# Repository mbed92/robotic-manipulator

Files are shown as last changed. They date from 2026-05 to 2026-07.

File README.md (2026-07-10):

# robotic-manipulator

Robotic manipulator prototype on a workbench

A small robotic manipulator project controlled by an Arduino Nano through a
PCA9685 servo driver. The repository contains Arduino firmware, the kinematic
model, angle-to-PWM mapping, calibration constants, and PCB files. This is my side project, 
and I had a lot of fun working on it. 

## Structure

- [`arduino/robot_arm/robot_arm.ino`](arduino/robot_arm/robot_arm.ino) - main firmware sketch.
- [`arduino/robot_arm/kinematics.h`](arduino/robot_arm/kinematics.h) / [`kinematics.cpp`](arduino/robot_arm/kinematics.cpp) - forward kinematics, Jacobian IK step generation, and angle-to-PWM conversion.
- [`arduino/robot_arm/robot_calibration.h`](arduino/robot_arm/robot_calibration.h) - servo channels, joint limits, HOME pose, and arm dimensions.
- [`arduino/robot_arm/pca9685_servo_driver.h`](arduino/robot_arm/pca9685_servo_driver.h) / [`pca9685_servo_driver.cpp`](arduino/robot_arm/pca9685_servo_driver.cpp) - PCA9685 driver wrapper.
- [`docs/bom.md`](docs/bom.md) - V1 prototype bill of materials.
- [`docs/lessons-learned.md`](docs/lessons-learned.md) - practical notes from calibration, IK debugging, and wiring.
- [`docs/TODO.md`](docs/TODO.md) - project task notes and planned improvements.
- [`pcb/`](pcb/) - KiCad PCB project.

## Hardware

The firmware assumes:

- an Arduino Nano microcontroller,
- a PCA9685 PWM driver on the I2C bus,
- six logical joints `J0-J5`, where `J0-J4` are part of the kinematic model
  and `J5` is the gripper.

The mechanical design and servo selection are based on material from
[Elektroweb](https://elektroweb.pl).

Joint indices map to PCA9685 channels defined in
`arduino/robot_arm/robot_calibration.h`.

## Kinematic Model

The manipulator is modeled as an arm with five kinematic joints:

- `J0` - base rotation around the vertical axis,
- `J1-J3` - pitch joints forming the planar arm chain,
- `J4` - local wrist/TCP rotation, independent of TCP position in the current model,
- `J5` - gripper, controlled outside the kinematic model.

TCP position is represented by the `TcpPose` structure:

- `reach_x_m` - reach in the arm plane, in meters,
- `reach_z_m` - TCP height, in meters,
- `yaw_rad` - base rotation, in radians.

Angle convention:

- all angles are in radians,
- `J1-J3 = 0` means that the arm segments point vertically upward,
- positive horizontal reach is computed with `sin(angle)`,
- height is computed with `cos(angle)`,
- `J0` controls the yaw of the whole arm,
- `J4` does not change the TCP position reported by forward kinematics.

Arm dimensions are stored in `JOINT_OFFSETS`:

- `L1` - vertical distance from base `J0` to shoulder `J1`,
- `L2-L4` - planar arm segment lengths,
- `L5` - offset from the last link to the TCP.

## Forward Kinematics

`forwardKinematics()` takes `J0-J4` joint angles and returns a `TcpPose`.
The computation accumulates consecutive pitch angles:

- `pitch_1 = J1`,
- `pitch_2 = J1 + J2`,
- `pitch_3 = J1 + J2 + J3`.

The TCP reach and height are then computed from link lengths `L2-L5`.
In the current model, `L4` and `L5` have the same direction as the final pitch
`J1 + J2 + J3`.

## Inverse Kinematics

The firmware uses an open-loop Jacobian IK trajectory generator based on the
commanded joint state:

- `computeJacobianIkStep()` is a pure numerical function. It computes one IK
  step from the current commanded joint angles, target, and configuration. It
  does not write PWM, wait, or access hardware.
- `moveToTargetJacobianIk()` in `robot_arm.ino` is the blocking hardware-facing
  trajectory generator. It calls the step function, checks limits, converts the
  next angles to PWM, writes the PCA9685 channels, waits until the next control
  period, and updates the commanded joint state.
- Before the planar DLS loop, the generator moves the explicitly commanded
  `J0`, `J3`, and `J4` axes toward their targets with the same fixed period and
  velocity limits. This gives the local Jacobian solve the intended `J3`
  geometry instead of starting from the vertical HOME singularity.

The IK task is:

- TCP reach,
- TCP height,
- base yaw,
- explicit `J3`,
- explicit `J4`.

Only the coupled planar subproblem `[reach, height, J3] <-> [J1, J2, J3]`
uses damped least squares. `J0` yaw and `J4` are handled as direct proportional
controllers with the same joint velocity and joint limit handling as the planar
joints. Task rows have explicit weights so meter and radian errors are scaled
before the DLS solve.

The solver limits joint velocity by computing a global `alpha` scale. If any
requested joint velocity exceeds its limit, the whole `q_dot` vector is scaled
by the smallest required ratio. For example, if a joint requests `3 rad/s` and
the limit is `2 rad/s`, the whole command is scaled by `2/3`. The current
default joint velocity limit is `0.5 rad/s` for each kinematic joint.

The default motion configuration uses a `20 ms` control period and allows up to
`500` iterations per target. With the default period this gives a maximum of
about `10 s` for one blocking target move before the target is reported as not
converged.

Joint limits also shrink the global step before failing the motion. A target is
reported as blocked only when the step scale is effectively exhausted while the
task error is still too large. The blocking motion loop also detects lack of
progress so the robot does not spend several seconds making tiny noisy motions
near an unreachable target.

Damped least squares does not remove physical singularities. Near a singular
configuration, some TCP directions are still not achievable by the mechanism.
DLS only prevents the numerical controller from asking for unbounded joint
velocities.

Because `J3` is an explicit task requirement and also part of the reach/height
kinematics, it restricts the reachable workspace. Some points that are
geometrically reachable with free `J3` may not be reachable when a specific
`J3` value is required.

Possible error statuses include:

- `OutOfReach` - the target did not converge within the configured iteration budget,
- `JointLimitViolation` - the current or computed command violates joint limits,
- `JointLimitBlocked` - joint limits prevent useful progress toward the target,
- `NoProgress` - the solver stopped reducing the normalized task error,
- `InvalidInput` - the input contains invalid values, such as `NaN` or infinity.

## Control Rules

The current firmware executes a fixed pick-and-place demo sequence during
startup:

1. `TARGET1` through `TARGET11` in `robot_arm.ino` define target `TcpPose`
   values, explicit `J3`, explicit `J4`, and gripper state.
2. `setup()` initializes the PCA9685, sends the arm to `ZERO`/HOME, and opens
   the gripper.
3. The robot moves through a blocking fixed-period Jacobian IK sequence: ready
   pose, pick-side yaw, descend, close gripper, lift, carry across a larger
   base rotation, descend, open gripper, retreat, and return to HOME.
4. The final HOME return is a normal Jacobian IK target, not a direct
   all-servo zero command.
5. Once the sequence is complete, `loop()` stays idle.

This is not closed-loop feedback from joint sensors. It is an open-loop
trajectory generator that assumes the commanded state is a reasonable estimate
of the servo state. Every new target and transition should still be tested
carefully on hardware.

## V1 Limitations

- No closed-loop feedback from joints.
- The Jacobian IK trajectory generator is blocking during the fixed demo
  sequence.
- IK solves TCP position and base yaw, not full 6D pose.
- `J3` and `J4` are explicit task inputs; `J3` constrains reachable TCP
  positions.
- Calibration is specific to this physical build and should not be copied
  blindly.
- Servo limits are conservative to avoid mechanical stops.

## Angle-To-PWM Mapping

`jointAnglesToPwmUs()` uses calibration values from `JOINT_CALIBRATIONS`.
For each joint, the calibration defines:

- PCA9685 channel,
- `pwm_min_us`, `pwm_zero_us`, `pwm_max_us`,
- `angle_min_rad`, `angle_zero_rad`, `angle_max_rad`.

The mapping is piecewise linear:

- from `angle_min_rad` to `angle_zero_rad`,
- from `angle_zero_rad` to `angle_max_rad`.

This also supports reversed servos, for example when `pwm_min_us` is greater
than `pwm_max_us`. The current `J3` calibration is one such case.

The `J5` gripper is controlled separately:

- `Open` uses `pwm_min_us`,
- `Closed` uses `pwm_max_us`.

## Lessons Learned

The main practical lessons are:

- mechanical zero is set by servo horn mounting first, then refined with
  `pwm_zero_us`,
- each joint needs its own zero, min, max, sign direction, and mechanical-stop
  check,
- IK commands should be sanity-checked by running FK on the resulting joint
  angles,
- Arduino logic power and servo power should be separated, with a common ground.

See [`docs/lessons-learned.md`](docs/lessons-learned.md) for the detailed notes.

## Startup Safety

Before testing on the manipulator, check:

- whether the target is within `JOINT_CALIBRATIONS` limits,
- whether `J3` and `J4` can cause a mechanical collision,
- whether the gripper PWM values are calibrated correctly,
- whether the open-loop IK motion can hit mechanical stops,
- whether the servo power supply is sufficient for multi-joint motion under load.

The safest test sequence is to compile first, then test without load, and only
then move with the final tool or object.

## Related Material

For broader teaching material on forward and inverse kinematics, see
[robotics-ai-classes](https://github.com/mbed92/robotics-ai-classes). That
repository contains ROS-based class exercises for FK and IK on a robotic
manipulator.

## Validation

Use Arduino CLI to validate firmware before testing on hardware:

```sh
arduino-cli compile --fqbn arduino:avr:nano arduino/robot_arm
```

For throwaway local builds, specify an explicit build path so generated
artifacts do not end up in the repository:

```sh
arduino-cli compile --fqbn arduino:avr:nano --build-path /tmp/robot_arm_build arduino/robot_arm
```

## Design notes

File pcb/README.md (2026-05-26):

# PCB Wiring

## Connections

- Laptop USB -> Arduino USB
- Arduino +5V -> PCA9685 VCC/VDD
- Arduino GND -> PCA9685 GND/VSS
- Arduino SDA (pin A4) -> PCA9685 SDA
- Arduino SCL (pin A5) -> PCA9685 SCL
- PSU +5V -> PCA9685 V+
- PSU GND -> PCA9685 GND
- SERVO1..6 PWM -> PCA9685 CH1..6 PWM
- SERVO1..6 5V -> PCA9685 CH1..6 5V
- SERVO1..6 GND -> PCA9685 CH1..6 GND

## Important Notes

- Arduino does NOT power the servos.
- Servos are powered directly from PSU.
- All grounds must be connected together.
- PCA9685 generates hardware PWM signals.

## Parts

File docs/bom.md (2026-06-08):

# Bill of Materials

This document lists the main components used in the V1 desktop robotic manipulator build.

The goal of this BOM is not to define a production-ready design, but to document the exact hardware used for the first working prototype.

## Main hardware

| Category | Component | Model / specification | Qty | Role in project | Notes |
| --- | --- | ---: | ----: | --- | --- |
| Mechanical kit | 6DOF robotic arm kit | Metal 6DOF arm with gripper | 1 | Main robot structure | Includes metal frame, gripper, servo horns, screws, bearings, cable sleeving and zip ties. |
| Servo | High-torque servo | MG996R | 6 | Arm joints and gripper actuation | Hobby servos used for all actuated joints. Real range and zero position must be calibrated per joint. |
| Controller | Arduino-compatible board | DFRduino Nano V4.0 / Arduino Nano compatible | 1 | Main microcontroller | Runs FK/IK, calibration mapping and servo commands. |
| Servo PWM driver | PCA9685 PWM servo driver | I2C PWM driver | 1 | Generates PWM signals for servos | Driven over I2C from Arduino. Servo power must be provided separately through the servo power rail. |
| Power supply | AC/DC switching PSU | POS-50-5-C2, 5 V / 10 A / 50 W | 1 | Main 5 V power supply for servos | Provides power for the servo rail. Do not power the servos from Arduino 5 V. |
| Servo tester | 3-channel servo tester | Generic 3-channel tester | 1 | Manual servo testing and centering | Used before connecting servos to PCA9685. Useful for checking servo health and approximate range. |
| Multimeter | Digital multimeter | UNI-T UT33A+ | 1 | Voltage and continuity checks | Used to verify PSU output, common GND and basic wiring. |
| Capacitor | Electrolytic capacitor | 1000 µF / 25 V, THT | 5 | Servo rail decoupling | Used near the servo power rail to reduce voltage dips caused by servo load transients. |
| Switch | Rocker switch | IRS-101-8C/D, 12 VDC / 20 A | 1 | Manual power switch | Used as a convenient switch in the prototype. Check ratings carefully before using in a final build. |
| Cable | USB cable | microUSB B to USB-A | 1 | Arduino programming and serial monitor | Used for firmware upload and debug output. |
| Wires | Jumper wires | 20 cm M-M, F-F, M-F set | 1 set | Low-current signal wiring | Useful for I2C and prototype wiring. Do not use thin jumpers for high-current servo power distribution. |

## Servo details

| Parameter | Value | Notes |
| --- | ---: | --- |
| Servo model | MG996R | Metal gear hobby servo. |
| Nominal operating voltage  | 4.8–7.2 V | The V1 build uses a 5 V supply. |
| Recommended kit voltage | 5–6 V | Matches the mechanical kit recommendation. |
| Approximate rotation range | ~120° | Treat this as approximate. Actual usable range depends on mechanical mounting and joint limits. |
| Stall current | ~2.5 A at 6 V | Important for power sizing. Multiple servos can create large transient current draw. |
| Signal period | 20 ms / 50 Hz | Standard hobby servo PWM. |
| Signal wire | Yellow / orange | PWM signal. |
| Power wire | Red | Servo VCC. |
| Ground wire | Brown | Servo GND. |

## Power architecture

The prototype uses separated logic and servo power:

| Rail | Source | Consumers | Notes |
| --- | --- | --- | --- |
| Logic 5 V | Arduino USB / Arduino 5 V rail | Arduino, PCA9685 logic side | Used only for logic-level electronics.  |
| Servo 5 V | External 5 V / 10 A PSU | PCA9685 servo V+ rail, servos | Used for servo power. |
| GND | Common ground | Arduino, PCA9685, PSU, servos | All grounds must be connected together. |

Important wiring rule:

```text
Arduino GND  --------+
PCA9685 GND ---------+---- common GND
PSU GND ------------+
Servo GND ----------+
```

The servos must not be powered directly from the Arduino 5 V pin. The Arduino controls the PWM driver, but the servo current comes from the external PSU.

## Wiring summary

| Connection | From | To | Notes |
| --- | --- | --- | --- |
| I2C SDA | Arduino SDA / A4 | PCA9685 SDA | Logic signal. |
| I2C SCL | Arduino SCL / A5 | PCA9685 SCL | Logic signal. |
| Logic power | Arduino 5 V | PCA9685 VCC / VDD | Logic power only. |
| Common ground | Arduino GND | PCA9685 GND, PSU GND | Required for PWM signal reference. |
| Servo power | PSU +5 V | PCA9685 V+ | High-current servo rail. |
| Servo ground  | PSU GND | PCA9685 GND / servo GND | Shared return path. |
| Servo PWM | PCA9685 channel PWM | Servo signal wire | One channel per servo. |

## Tools and consumables

| Component | Purpose | Notes |
| --- | --- | --- |
| Multimeter | Voltage, polarity and continuity checks | Verify 5 V before connecting servos. |
| Servo tester | Manual servo range and centering tests  | Useful before writing firmware. |
| Jumper wires | Prototype signal wiring | Use only for low-current paths. |
| Thicker power wires | Servo power distribution | Recommended for PSU-to-servo power bus. |
| Zip ties / sleeving | Cable management | Cables must not restrict joint motion.  |
| Small screwdriver set | Mechanical assembly | Required for frame and servo horns. |

## Known substitutions

| Original component | Possible substitute | Requirements |
| --- | --- | --- |
| DFRduino Nano V4.0 | Arduino Nano / Uno compatible | Must support I2C and Arduino Servo/PWM-related libraries. |
| PCA9685 PWM board  | Any PCA9685 16-channel servo driver | Must expose VCC/VDD, V+, GND, SDA, SCL and servo headers. |
| 5 V / 10 A PSU | Other 5–6 V DC PSU | Must provide enough current for multiple servos. Use current margin. |
| MG996R servos | Similar metal gear hobby servos | Requires recalibration of PWM limits, zero positions and joint directions. |

## Safety notes

* Verify PSU output voltage before connecting the servo rail.
* Do not power the servos from the Arduino.
* Keep all grounds common.
* Start with one servo connected during early tests.
* Keep PWM limits conservative until each joint is calibrated.
* Check that cables do not restrict motion at any joint.
* Keep a physical way to cut servo power during first motion tests.

## V1 limitations

This BOM describes the first working prototype. It is not a production-ready electrical design.

Known limitations:

* No current sensing on individual servos.
* No emergency stop circuit.
* No fuse selected specifically for the final DC servo rail.
* No dedicated high-current PCB or power distribution board.
* Servo power distribution is prototype-grade.
* Cable strain relief should be improved before extended operation.
* Servo calibration is specific to this mechanical build.

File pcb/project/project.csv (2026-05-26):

Reference | Qty | Value | DNP | Exclude from BOM | Exclude from Board | Footprint | Datasheet
A1 | 1 | Arduino_Nano_v3.x |  |  |  | Module:Arduino_Nano | http://www.mouser.com/pdfdocs/Gravitech_Arduino_Nano3_0.pdf
C1 | 1 | 1000uF / 25V |  |  |  | Capacitor_THT:CP_Radial_D10.0mm_P5.00mm
J1 | 1 | PCA9685_I2C |  |  | Wykluczono z płytki
J2 | 1 | SERVO_BASE |  |  |  | Connector_PinHeader_2.54mm:PinHeader_1x03_P2.54mm_Vertical
J3 | 1 | SERVO_SHOULDER |  |  |  | Connector_PinHeader_2.54mm:PinHeader_1x03_P2.54mm_Vertical
J4 | 1 | SERVO_ELBOW |  |  |  | Connector_PinHeader_2.54mm:PinHeader_1x03_P2.54mm_Vertical
J5 | 1 | SERVO_WRIST_PITCH |  |  |  | Connector_PinHeader_2.54mm:PinHeader_1x03_P2.54mm_Vertical
J6 | 1 | SERVO_WRIST_ROT |  |  |  | Connector_PinHeader_2.54mm:PinHeader_1x03_P2.54mm_Vertical
J7 | 1 | SERVO_GRIPPER |  |  |  | Connector_PinHeader_2.54mm:PinHeader_1x03_P2.54mm_Vertical
J8 | 1 | PWM1 |  |  | Wykluczono z płytki
J9 | 1 | PWM2 |  |  | Wykluczono z płytki
J10 | 1 | PWM3 |  |  | Wykluczono z płytki
J11 | 1 | PWM4 |  |  | Wykluczono z płytki
J12 | 1 | PWM5 |  |  | Wykluczono z płytki
J13 | 1 | PWM6 |  |  | Wykluczono z płytki
J14 | 1 | POS-50-5-C2 |  |  |  | TerminalBlock:TerminalBlock_MaiXu_MX126-5.0-02P_1x02_P5.00mm

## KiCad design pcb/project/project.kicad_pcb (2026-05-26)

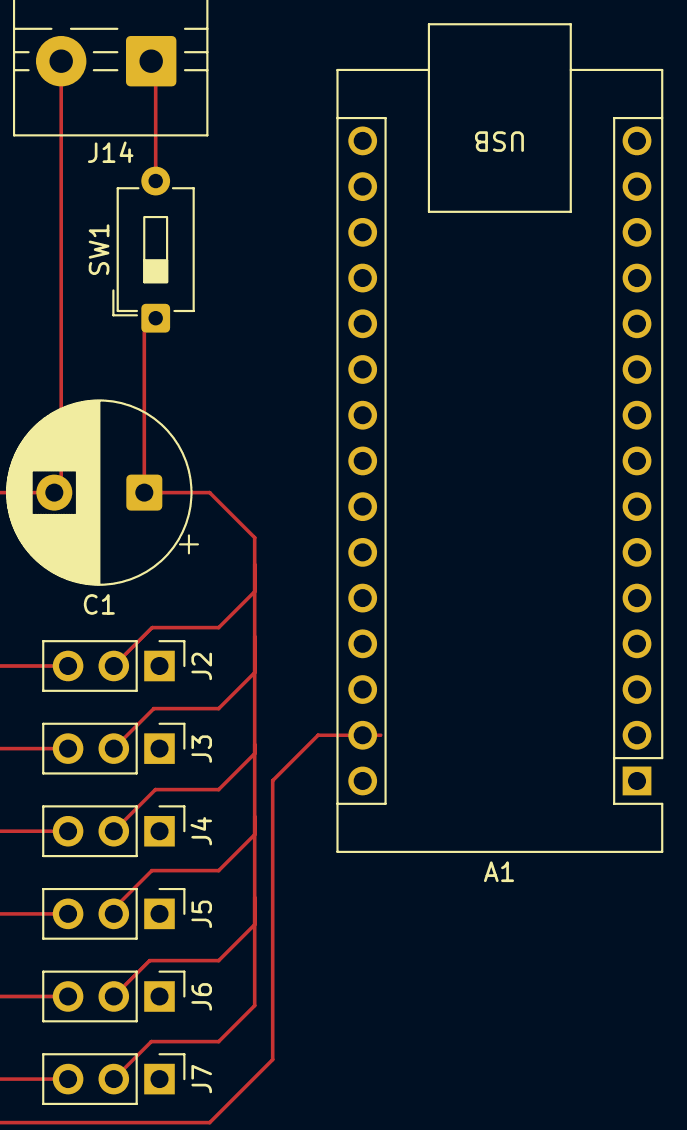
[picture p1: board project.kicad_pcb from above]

Board: 2 copper layers, 10 parts (0 on the bottom side), 3 nets.

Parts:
A1: Arduino_Nano_v3.x; Arduino_Nano
C1: 1000uF / 25V; CP_Radial_D10.0mm_P5.00mm
J2: SERVO_BASE; PinHeader_1x03_P2.54mm_Vertical
J3: SERVO_SHOULDER; PinHeader_1x03_P2.54mm_Vertical
J4: SERVO_ELBOW; PinHeader_1x03_P2.54mm_Vertical
J5: SERVO_WRIST_PITCH; PinHeader_1x03_P2.54mm_Vertical
J6: SERVO_WRIST_ROT; PinHeader_1x03_P2.54mm_Vertical
J7: SERVO_GRIPPER; PinHeader_1x03_P2.54mm_Vertical
J14: POS-50-5-C2; TerminalBlock_MaiXu_MX126-5.0-02P_1x02_P5.00mm
SW1: SW_SPST; SW_DIP_SPSTx01_Slide_6.7x4.1mm_W7.62mm_P2.54mm_LowProfile

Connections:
/+5V_IN: J14.1, SW1.2 (B)
/+5V_SERVO: C1.1, J2.2, J3.2, J4.2, J5.2, J6.2, J7.2, SW1.1 (A)
/GND: A1.29 (GND), C1.2, J2.3, J3.3, J4.3, J5.3, J6.3, J7.3, J14.2

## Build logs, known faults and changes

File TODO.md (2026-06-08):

# TODO

## Accept target commands from an external controller

Current state:
- The firmware uses a manually edited `const ArmTarget TARGET` in `robot_arm.ino`.
- Changing the target TCP pose, `J3`, `J4`, or gripper state requires editing and reflashing the Arduino sketch.
- This is useful for a simple bring-up demo, but it is not a practical control interface.

Target state:
- Receive target commands from an external controller over a board-level bus such as I2C or SPI.
- The external controller could be ROS running on a Jetson or PC.
- Keep the Arduino responsible for low-level command validation, IK, angle-to-PWM conversion, and servo output.
- Keep the higher-level system responsible for planning, sequencing, and deciding what target should be sent next.

Recommended first implementation:
- Define a small binary command frame for `TcpPose`, requested `J3`, requested `J4`, and gripper command.
- Include a protocol version, command type, payload length, and checksum or CRC.
- Return an explicit status response such as accepted, invalid input, out of reach, or joint limit violation.
- Start with one command-at-a-time execution before adding queues or streaming trajectories.

Main trade-off:
- I2C is simple and common for embedded peripherals, but the Arduino must behave predictably as a bus device.
- SPI can provide cleaner timing and higher throughput, but needs more wiring and a slightly stricter framing design.
- A serial transport may be easier for early debugging, even if I2C or SPI remains the target hardware interface.

## Generate coordinated multi-joint ramps

Current state:
- Ramp generation is disabled for now.
- `Pca9685ServoDriver::setServoUs()` writes the target PWM immediately.
- Demo scripts still call `setServoUs()` joint by joint, but each call is now a direct PWM update.

Target state:
- Generate the ramp at the motion/script level, where targets for all joints are known at the same time.
- Keep the PCA9685 driver focused on low-level PWM output, using immediate channel writes for each ramp sample.
- For each ramp step, compute intermediate PWM values for all joints and write all channels before delaying.

Recommended first implementation:
- Add a helper such as `moveAllJointsRamp(targets_us)` in the main demo/control script.
- Read or track the current PWM for each joint.
- Compute the maximum required delta across all joints.
- Step from current values to target values proportionally so all joints finish together.
- Use `setServoUsImmediate()` for each channel inside each ramp sample.

Main trade-off:
- A blocking `moveAllJointsRamp()` is acceptable as a simple first step and fixes sequential joint motion.
- A later version should use a non-blocking `millis()`-based trajectory update if the robot needs responsiveness to commands, sensors, or emergency stop handling during motion.

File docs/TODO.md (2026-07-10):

# TODO

## Accept target commands from an external controller

Current state:
- The firmware uses a hardcoded `TARGETS[]` pick-and-place demo sequence in `robot_arm.ino`.
- Changing the target TCP pose, `J3`, `J4`, or gripper state requires editing and reflashing the Arduino sketch.
- This is useful for local demo tuning, but it is not a practical control interface.

Target state:
- Receive target commands from an external controller over a board-level bus such as I2C or SPI.
- The external controller could be ROS running on a Jetson or PC.
- Keep the Arduino responsible for low-level command validation, IK, angle-to-PWM conversion, and servo output.
- Keep the higher-level system responsible for planning, sequencing, and deciding what target should be sent next.

Recommended first implementation:
- Define a small binary command frame for `TcpPose`, requested `J3`, requested `J4`, and gripper command.
- Include a protocol version, command type, payload length, and checksum or CRC.
- Return an explicit status response such as accepted, invalid input, out of reach, or joint limit violation.
- Start with one command-at-a-time execution before adding queues or streaming trajectories.

Main trade-off:
- I2C is simple and common for embedded peripherals, but the Arduino must behave predictably as a bus device.
- SPI can provide cleaner timing and higher throughput, but needs more wiring and a slightly stricter framing design.
- A serial transport may be easier for early debugging, even if I2C or SPI remains the target hardware interface.

## Make Jacobian IK motion non-blocking

Current state:
- The main demo uses a blocking open-loop Jacobian IK trajectory generator.
- Each generated step writes all kinematic joint PWM targets, waits until the next fixed control period, and updates the commanded joint state.
- `Pca9685ServoDriver::setServoUs()` remains a low-level immediate PWM write.

Target state:
- Keep `computeJacobianIkStep()` as a pure numerical function.
- Move the blocking loop into a non-blocking `millis()`-scheduled motion state machine when the robot needs to accept commands, status requests, or stop conditions during motion.
- Keep the PCA9685 driver focused on low-level PWM output.

Recommended first implementation:
- Define an active motion state containing target, config, last deadline, current commanded angles, last error, and no-progress counter.
- On each loop tick, run at most one Jacobian IK step when the next period deadline has elapsed.
- Return explicit status for running, converged, invalid input, joint-limit blocked, no progress, and missed deadline.
- Add a way to cancel the active motion before adding command queues.

Main trade-off:
- The current blocking implementation is simpler for bring-up and keeps timing easy to inspect.
- A non-blocking scheduler is more complex, but it is needed before the Arduino can safely handle external command streaming or emergency-stop style inputs during motion.

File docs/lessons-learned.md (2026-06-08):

# Lessons Learned

This project is hardware-adjacent, so the useful lessons are mostly about
keeping the software model honest against the physical manipulator.

## Servo Zero Is Mechanical First

`1500 us` does not automatically mean a good-looking robot pose. It is only the
electrical midpoint of a typical hobby servo command range.

Mechanical zero should be established by mounting each servo horn so the joint
is physically at its intended zero position when the servo is commanded to its
zero PWM. Only after that should `pwm_zero_us` be calibrated in
`arduino/robot_arm/robot_calibration.h`.

If the horn is installed one spline off, software calibration can hide the
symptom, but the usable range becomes asymmetric. The joint can then hit a
mechanical stop before the configured software limit is reached.

## Servo Range Is Not Always 180 Degrees

The real MG996R range does not have to match a full 180 degrees. A commonly
referenced MG996R datasheet describes about 120 degrees of movement, which is
roughly 60 degrees in each direction from center:
[MG996R datasheet](https://mm.digikey.com/Volume0/opasdata/d220001/medias/docus/204/MG996R.pdf).

That is why the current calibration uses conservative joint limits of about
`-60` to `+60` degrees:

```cpp
constexpr float JOINT_ANGLE_MIN_RAD = -1.0472f; // -60 degrees
constexpr float JOINT_ANGLE_MAX_RAD = 1.0472f; // 60 degrees
```

This is a practical safety choice, not just a kinematic preference. It keeps
software commands closer to the range the servos and mechanism can actually
reach.

## Calibrate Every Joint Separately

Each joint needs its own calibration pass:

- physical zero,
- minimum safe PWM and angle,
- maximum safe PWM and angle,
- sign direction,
- mechanical-stop margin.

Do not assume that all servos are mounted with the same direction. In this
project, `J3` is reversed in `JOINT_CALIBRATIONS`:

```cpp
{3, 2000, 1500, 1000, JOINT_ANGLE_MIN_RAD, JOINT_ANGLE_ZERO_RAD, JOINT_ANGLE_MAX_RAD},
```

That is intentionally different from the normal ordering used by most other
joints:

```cpp
{0, 1000, 1500, 2000, JOINT_ANGLE_MIN_RAD, JOINT_ANGLE_ZERO_RAD, JOINT_ANGLE_MAX_RAD},
```

The reversed PWM order is clearer and safer than compensating for the inversion
somewhere else in the kinematic code.

## Verify IK With FK

Inverse kinematics should be debugged by comparing the requested IK target with
the forward-kinematics result of the computed joint angles.

The firmware already does this in `robot_arm.ino`: after solving IK and
converting the command, it runs `forwardKinematics(angles)` and prints the
model TCP pose. That makes it easier to catch:

- sign errors,
- wrong link lengths,
- joint-limit surprises,
- IK solutions that are mathematically valid but not the solution expected on
  the real arm.

This is one of the most useful checks before trusting a new target on hardware.

## Keep The Kinematic Model As Simple As The Robot

The kinematic model should match the actual mechanism instead of solving a more
general problem than the robot needs.

In this project, the IK can stay simple:

- `J0` provides independent yaw,
- `J1-J3` form a planar `Reacher2D` chain,
- `J4` is a user-defined local wrist/TCP rotation,
- `J5` is the gripper and is controlled outside the kinematic model.

This keeps the firmware easier to debug and reduces the number of ambiguous IK
solutions.

## Power Wiring Is Part Of The Control System

Common ground and separated power domains are not details. They are conditions
for the robot to work reliably.

The PCB wiring follows this split:

- Arduino powers the PCA9685 logic side through VCC/VDD,
- the external PSU powers PCA9685 `V+` and the servos,
- Arduino ground, PSU ground, PCA9685 ground, and servo grounds are connected
  together.

The Arduino should not power the servos. The servo rail can draw high current
and create voltage drops or resets that should not be imposed on the logic
supply. At the same time, all grounds must be common or the PWM signal has no
shared electrical reference.

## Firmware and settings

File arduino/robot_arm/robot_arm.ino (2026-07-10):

/**
 * Fixed pick-and-place demo sequence.
 *
 * setup() moves the robot to HOME/ZERO, opens the gripper, executes the
 * TARGETS[] sequence with the open-loop Jacobian IK trajectory generator, then
 * returns to HOME through the same controlled motion path. loop() stays idle.
 */

#include <Wire.h>
#include <math.h>

#include "kinematics.h"
#include "pca9685_servo_driver.h"
#include "robot_calibration.h"

enum class GripperCommand {
    Closed,
    Open,
};

struct ArmTarget {
    TcpPose tcp_pose;
    float j3_rad;
    float j4_rad;
    GripperCommand gripper;
};

struct JacobianIkResult {
    KinematicsStatus status;
    uint16_t iterations;
    bool missed_deadline;
    JacobianIkStepResult last_step;
    ArmJointPwmUs last_pwm;
};

const ArmTarget TARGET1 = {
    {0.140f, 0.360f, 0.0f},
    0.900f,
    0.0f,
    GripperCommand::Open,
};

const ArmTarget TARGET2 = {
    {0.140f, 0.360f, -0.95f},
    0.900f,
    -0.7f,
    GripperCommand::Open,
};

const ArmTarget TARGET3 = {
    {0.160f, 0.350f, -0.95f},
    0.900f,
    -0.7f,
    GripperCommand::Open,
};

const ArmTarget TARGET4 = {
    {0.160f, 0.350f, -0.95f},
    0.900f,
    -0.7f,
    GripperCommand::Closed,
};

const ArmTarget TARGET5 = {
    {0.140f, 0.360f, -0.95f},
    0.900f,
    -0.7f,
    GripperCommand::Closed,
};

const ArmTarget TARGET6 = {
    {0.150f, 0.360f, 0.0f},
    0.900f,
    0.0f,
    GripperCommand::Closed,
};

const ArmTarget TARGET7 = {
    {0.140f, 0.360f, 0.95f},
    0.900f,
    0.7f,
    GripperCommand::Closed,
};

const ArmTarget TARGET8 = {
    {0.160f, 0.350f, 0.95f},
    0.900f,
    0.7f,
    GripperCommand::Closed,
};

const ArmTarget TARGET9 = {
    {0.160f, 0.350f, 0.95f},
    0.900f,
    0.7f,
    GripperCommand::Open,
};

const ArmTarget TARGET10 = {
    {0.140f, 0.360f, 0.95f},
    0.900f,
    0.7f,
    GripperCommand::Open,
};

const ArmTarget TARGET11 = {
    {0.0f, 0.489f, 0.0f},
    0.0f,
    0.0f,
    GripperCommand::Open,
};

const ArmTarget TARGETS[] = {
    TARGET1,
    TARGET2,
    TARGET3,
    TARGET4,
    TARGET5,
    TARGET6,
    TARGET7,
    TARGET8,
    TARGET9,
    TARGET10,
    TARGET11,
};

constexpr unsigned long STEP_DELAY_MS = 500;

Pca9685ServoDriver servo_driver;
ArmJointAngles commanded_angles;

bool moveToArmTarget(const char *name, const ArmTarget &target, const JacobianIkConfig &config);
JacobianIkResult moveToTargetJacobianIk(
    ArmJointAngles &commanded_angles,
    const JacobianIkTarget &target,
    const JacobianIkConfig &config);
JacobianIkTarget toJacobianIkTarget(const ArmTarget &target);
void sendZeroCommand();
bool sendKinematicJointCommand(const ArmJointAngles &angles, ArmJointPwmUs &pwm);
void sendGripperCommand(GripperCommand command);
void waitUntilNextPeriod(unsigned long period_start_ms, unsigned long period_ms, bool &missed_deadline);
bool moveExplicitJointTargets(
    ArmJointAngles &commanded_angles,
    const JacobianIkTarget &target,
    const JacobianIkConfig &config,
    JacobianIkResult &result);
float limitedAngleStep(float error_rad, float velocity_limit_rad_s, float dt_s);
float normalizedTaskError(const JacobianIkStepResult &step, const JacobianIkConfig &config);
void printTargetDiagnostics(
    const ArmTarget &target,
    const JacobianIkResult &result,
    const ArmJointAngles &angles);
void printArmJointAngles(const ArmJointAngles &angles);
uint16_t gripperCommandToPwmUs(GripperCommand command);

void setup() {
    Serial.begin(115200);

    if (!servo_driver.begin()) {
        Serial.println(F("PCA9685 init failed"));
        return;
    }

    delay(100);
    commanded_angles = robotHomeJointAngles();
    const JacobianIkConfig ik_config = defaultJacobianIkConfig();

    sendZeroCommand();
    sendGripperCommand(GripperCommand::Open);
    Serial.println(F("ZERO command sent"));
    delay(STEP_DELAY_MS);

    for (uint8_t i = 0; i < sizeof(TARGETS) / sizeof(TARGETS[0]); ++i) {
        if (!moveToArmTarget("TARGET", TARGETS[i], ik_config)) {
            Serial.println(F("Target command failed; sequence stopped"));
            return;
        }
        delay(STEP_DELAY_MS);
    }

    Serial.println(F("Target sequence complete"));
}

void loop() {
}

bool moveToArmTarget(const char *name, const ArmTarget &target, const JacobianIkConfig &config) {
    Serial.print(F("Moving to "));
    Serial.println(name);

    const JacobianIkResult result = moveToTargetJacobianIk(
        commanded_angles,
        toJacobianIkTarget(target),
        config);
    printTargetDiagnostics(target, result, commanded_angles);
    if (result.status != KinematicsStatus::Ok) {
        return false;
    }

    sendGripperCommand(target.gripper);
    Serial.print(name);
    Serial.println(F(" motion complete"));
    return true;
}

JacobianIkResult moveToTargetJacobianIk(
    ArmJointAngles &commanded_angles,
    const JacobianIkTarget &target,
    const JacobianIkConfig &config) {
    JacobianIkResult result = {
        KinematicsStatus::OutOfReach,
        0,
        false,
        {},
        {0, 0, 0, 0, 0},
    };

    const unsigned long period_ms = max(1UL, static_cast<unsigned long>(config.dt_s * 1000.0f + 0.5f));
    float best_error = 3.402823466e+38f;
    uint8_t no_progress_count = 0;

    if (!moveExplicitJointTargets(commanded_angles, target, config, result)) {
        return result;
    }

    for (uint16_t iteration = result.iterations; iteration < config.max_iterations; ++iteration) {
        const unsigned long period_start_ms = millis();
        const JacobianIkStepResult step = computeJacobianIkStep(
            commanded_angles,
            target,
            config);

        result.iterations = iteration + 1;
        result.last_step = step;

        if (step.status != KinematicsStatus::Ok) {
            result.status = step.status;
            return result;
        }

        if (step.converged) {
            result.status = KinematicsStatus::Ok;
            return result;
        }

        ArmJointPwmUs pwm = {0, 0, 0, 0, 0};
        if (!sendKinematicJointCommand(step.next_angles, pwm)) {
            result.status = KinematicsStatus::JointLimitViolation;
            return result;
        }

        commanded_angles = step.next_angles;
        result.last_pwm = pwm;

        const float error = normalizedTaskError(step, config);
        if (best_error - error > config.min_error_progress) {
            best_error = error;
            no_progress_count = 0;
        } else if (++no_progress_count >= config.no_progress_iteration_limit) {
            result.status = KinematicsStatus::NoProgress;
            waitUntilNextPeriod(period_start_ms, period_ms, result.missed_deadline);
            return result;
        }

        waitUntilNextPeriod(period_start_ms, period_ms, result.missed_deadline);
    }

    result.status = KinematicsStatus::OutOfReach;
    return result;
}

JacobianIkTarget toJacobianIkTarget(const ArmTarget &target) {
    return {
        target.tcp_pose,
        target.j3_rad,
        target.j4_rad,
    };
}

void sendZeroCommand() {
    Serial.println(F("Sending ZERO command"));

    for (uint8_t i = 0; i < ROBOT_TOTAL_JOINT_COUNT; ++i) {
        const JointCalibration &joint = JOINT_CALIBRATIONS[i];
        servo_driver.setServoUs(joint.channel, joint.pwm_zero_us);
    }
    commanded_angles = robotHomeJointAngles();
}

bool sendKinematicJointCommand(const ArmJointAngles &angles, ArmJointPwmUs &pwm) {
    const KinematicsResult<ArmJointPwmUs> pwm_result = jointAnglesToPwmUs(angles, JOINT_CALIBRATIONS);
    if (pwm_result.status != KinematicsStatus::Ok) {
        Serial.print(F("Target PWM failed status="));
        Serial.println(kinematicsStatusName(pwm_result.status));
        return false;
    }

    pwm = pwm_result.value;
    const uint16_t pwm_values[ROBOT_KINEMATIC_JOINT_COUNT] = {
        pwm.j0_us,
        pwm.j1_us,
        pwm.j2_us,
        pwm.j3_us,
        pwm.j4_us,
    };

    for (uint8_t i = 0; i < ROBOT_KINEMATIC_JOINT_COUNT; ++i) {
        servo_driver.setServoUs(
            JOINT_CALIBRATIONS[i].channel,
            pwm_values[i]);
    }

    return true;
}

void sendGripperCommand(GripperCommand command) {
    const JointCalibration &gripper = JOINT_CALIBRATIONS[ROBOT_GRIPPER_JOINT_INDEX];
    servo_driver.setServoUs(gripper.channel, gripperCommandToPwmUs(command));
}

void waitUntilNextPeriod(unsigned long period_start_ms, unsigned long period_ms, bool &missed_deadline) {
    const unsigned long elapsed_ms = millis() - period_start_ms;
    if (elapsed_ms < period_ms) {
        delay(period_ms - elapsed_ms);
    } else {
        missed_deadline = true;
    }
}

bool moveExplicitJointTargets(
    ArmJointAngles &commanded_angles,
    const JacobianIkTarget &target,
    const JacobianIkConfig &config,
    JacobianIkResult &result) {
    const unsigned long period_ms = max(1UL, static_cast<unsigned long>(config.dt_s * 1000.0f + 0.5f));

    while (result.iterations < config.max_iterations) {
        const float yaw_error_rad = target.tcp_pose.yaw_rad - commanded_angles.j0_rad;
        const float j3_error_rad = target.j3_rad - commanded_angles.j3_rad;
        const float j4_error_rad = target.j4_rad - commanded_angles.j4_rad;

        if (fabs(yaw_error_rad) <= config.angle_tolerance_rad &&
            fabs(j3_error_rad) <= config.angle_tolerance_rad &&
            fabs(j4_error_rad) <= config.angle_tolerance_rad) {
            return true;
        }

        const unsigned long period_start_ms = millis();
        ArmJointAngles next_angles = commanded_angles;
        next_angles.j0_rad += limitedAngleStep(
            yaw_error_rad,
            config.joint_velocity_limit_rad_s[0],
            config.dt_s);
        next_angles.j3_rad += limitedAngleStep(
            j3_error_rad,
            config.joint_velocity_limit_rad_s[3],
            config.dt_s);
        next_angles.j4_rad += limitedAngleStep(
            j4_error_rad,
            config.joint_velocity_limit_rad_s[4],
            config.dt_s);

        ArmJointPwmUs pwm = {0, 0, 0, 0, 0};
        if (!sendKinematicJointCommand(next_angles, pwm)) {
            result.status = KinematicsStatus::JointLimitViolation;
            return false;
        }

        commanded_angles = next_angles;
        result.last_pwm = pwm;
        result.iterations++;
        waitUntilNextPeriod(period_start_ms, period_ms, result.missed_deadline);
    }

    result.status = KinematicsStatus::OutOfReach;
    return false;
}

float limitedAngleStep(float error_rad, float velocity_limit_rad_s, float dt_s) {
    const float max_step_rad = velocity_limit_rad_s * dt_s;
    if (error_rad > max_step_rad) {
        return max_step_rad;
    }
    if (error_rad < -max_step_rad) {
        return -max_step_rad;
    }
    return error_rad;
}

float normalizedTaskError(const JacobianIkStepResult &step, const JacobianIkConfig &config) {
    float result = fabs(step.reach_error_m) / config.position_tolerance_m;
    const float z_error = fabs(step.z_error_m) / config.position_tolerance_m;
    if (z_error > result) {
        result = z_error;
    }
    const float yaw_error = fabs(step.yaw_error_rad) / config.angle_tolerance_rad;
    if (yaw_error > result) {
        result = yaw_error;
    }
    const float j3_error = fabs(step.j3_error_rad) / config.angle_tolerance_rad;
    if (j3_error > result) {
        result = j3_error;
    }
    const float j4_error = fabs(step.j4_error_rad) / config.angle_tolerance_rad;
    if (j4_error > result) {
        result = j4_error;
    }
    return result;
}

void printTargetDiagnostics(
    const ArmTarget &target,
    const JacobianIkResult &result,
    const ArmJointAngles &angles) {
    Serial.print(F("Target TCP reach_x_m="));
    Serial.print(target.tcp_pose.reach_x_m, 6);
    Serial.print(F(" reach_z_m="));
    Serial.print(target.tcp_pose.reach_z_m, 6);
    Serial.print(F(" yaw_rad="));
    Serial.print(target.tcp_pose.yaw_rad, 6);
    Serial.print(F(" requested_j3_rad="));
    Serial.print(target.j3_rad, 6);
    Serial.print(F(" requested_j4_rad="));
    Serial.println(target.j4_rad, 6);

    Serial.print(F("Jacobian IK status="));
    Serial.print(kinematicsStatusName(result.status));
    Serial.print(F(" iterations="));
    Serial.print(result.iterations);
    Serial.print(F(" missed_deadline="));
    Serial.print(result.missed_deadline ? F("yes") : F("no"));
    Serial.print(F(" alpha="));
    Serial.println(result.last_step.alpha, 6);

    Serial.print(F("Final errors reach_m="));
    Serial.print(result.last_step.reach_error_m, 6);
    Serial.print(F(" z_m="));
    Serial.print(result.last_step.z_error_m, 6);
    Serial.print(F(" yaw_rad="));
    Serial.print(result.last_step.yaw_error_rad, 6);
    Serial.print(F(" j3_rad="));
    Serial.print(result.last_step.j3_error_rad, 6);
    Serial.print(F(" j4_rad="));
    Serial.println(result.last_step.j4_error_rad, 6);

    printArmJointAngles(angles);

    const KinematicsResult<TcpPose> fk_result = forwardKinematics(angles);
    if (fk_result.status == KinematicsStatus::Ok) {
        Serial.print(F("Model FK reach_x_m="));
        Serial.print(fk_result.value.reach_x_m, 6);
        Serial.print(F(" reach_z_m="));
        Serial.print(fk_result.value.reach_z_m, 6);
        Serial.print(F(" yaw_rad="));
        Serial.println(fk_result.value.yaw_rad, 6);
    } else {
        Serial.print(F("Model FK failed status="));
        Serial.println(kinematicsStatusName(fk_result.status));
    }

    Serial.print(F("Last commanded PWM j0_us="));
    Serial.print(result.last_pwm.j0_us);
    Serial.print(F(" j1_us="));
    Serial.print(result.last_pwm.j1_us);
    Serial.print(F(" j2_us="));
    Serial.print(result.last_pwm.j2_us);
    Serial.print(F(" j3_us="));
    Serial.print(result.last_pwm.j3_us);
    Serial.print(F(" j4_us="));
    Serial.println(result.last_pwm.j4_us);
}

void printArmJointAngles(const ArmJointAngles &angles) {
    Serial.print(F("Commanded angles j0_rad="));
    Serial.print(angles.j0_rad, 6);
    Serial.print(F(" j1_rad="));
    Serial.print(angles.j1_rad, 6);
    Serial.print(F(" j2_rad="));
    Serial.print(angles.j2_rad, 6);
    Serial.print(F(" j3_rad="));
    Serial.print(angles.j3_rad, 6);
    Serial.print(F(" j4_rad="));
    Serial.println(angles.j4_rad, 6);
}

uint16_t gripperCommandToPwmUs(GripperCommand command) {
    const JointCalibration &gripper = JOINT_CALIBRATIONS[ROBOT_GRIPPER_JOINT_INDEX];
    return command == GripperCommand::Open ? gripper.pwm_min_us : gripper.pwm_max_us;
}

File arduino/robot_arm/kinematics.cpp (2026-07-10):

#include "kinematics.h"

#include <math.h>

constexpr float FULL_TURN_RAD = 6.28318530718f;
constexpr float IK_EPSILON = 0.000001f;

static bool isFiniteFloat(float value) {
    return !isnan(value) && !isinf(value);
}

static bool isValidOffsets(const JointOffsets &offsets) {
    return isFiniteFloat(offsets.l1_m) && offsets.l1_m >= 0.0f &&
           isFiniteFloat(offsets.l2_m) && offsets.l2_m >= 0.0f &&
           isFiniteFloat(offsets.l3_m) && offsets.l3_m >= 0.0f &&
           isFiniteFloat(offsets.l4_m) && offsets.l4_m >= 0.0f &&
           isFiniteFloat(offsets.l5_m) && offsets.l5_m >= 0.0f;
}

static bool isValidAngles(const ArmJointAngles &angles) {
    return isFiniteFloat(angles.j0_rad) &&
           isFiniteFloat(angles.j1_rad) &&
           isFiniteFloat(angles.j2_rad) &&
           isFiniteFloat(angles.j3_rad) &&
           isFiniteFloat(angles.j4_rad);
}

static bool isValidPose(const TcpPose &pose) {
    return isFiniteFloat(pose.reach_x_m) &&
           isFiniteFloat(pose.reach_z_m) &&
           isFiniteFloat(pose.yaw_rad);
}

static float normalizeAngleRad(float angle_rad) {
    while (angle_rad > PI) {
        angle_rad -= FULL_TURN_RAD;
    }
    while (angle_rad < -PI) {
        angle_rad += FULL_TURN_RAD;
    }
    return angle_rad;
}

static float angleDistanceRad(float a_rad, float b_rad) {
    return normalizeAngleRad(a_rad - b_rad);
}

static bool isWithinJointLimit(uint8_t joint_index, float angle_rad) {
    const JointCalibration &calibration = JOINT_CALIBRATIONS[joint_index];
    return angle_rad >= calibration.angle_min_rad &&
           angle_rad <= calibration.angle_max_rad;
}

static bool areWithinJointLimits(const ArmJointAngles &angles) {
    return isWithinJointLimit(0, angles.j0_rad) &&
           isWithinJointLimit(1, angles.j1_rad) &&
           isWithinJointLimit(2, angles.j2_rad) &&
           isWithinJointLimit(3, angles.j3_rad) &&
           isWithinJointLimit(4, angles.j4_rad);
}

ArmJointAngles robotHomeJointAngles() {
    return {
        ROBOT_HOME_J0_RAD,
        ROBOT_HOME_J1_RAD,
        ROBOT_HOME_J2_RAD,
        ROBOT_HOME_J3_RAD,
        ROBOT_HOME_J4_RAD,
    };
}

static float interpolatePwmUs(const JointCalibration &calibration, float angle_rad) {
    if (angle_rad >= calibration.angle_zero_rad) {
        const float angle_span = calibration.angle_max_rad - calibration.angle_zero_rad;
        const float pwm_span = static_cast<float>(calibration.pwm_max_us) -
                               static_cast<float>(calibration.pwm_zero_us);
        return static_cast<float>(calibration.pwm_zero_us) +
               ((angle_rad - calibration.angle_zero_rad) * pwm_span) / angle_span;
    }

    const float angle_span = calibration.angle_zero_rad - calibration.angle_min_rad;
    const float pwm_span = static_cast<float>(calibration.pwm_zero_us) -
                           static_cast<float>(calibration.pwm_min_us);
    return static_cast<float>(calibration.pwm_zero_us) -
           ((calibration.angle_zero_rad - angle_rad) * pwm_span) / angle_span;
}

static uint16_t lowerPwmBoundUs(const JointCalibration &calibration) {
    uint16_t lower_us = calibration.pwm_min_us;
    if (calibration.pwm_zero_us < lower_us) {
        lower_us = calibration.pwm_zero_us;
    }
    if (calibration.pwm_max_us < lower_us) {
        lower_us = calibration.pwm_max_us;
    }
    return lower_us;
}

static uint16_t upperPwmBoundUs(const JointCalibration &calibration) {
    uint16_t upper_us = calibration.pwm_min_us;
    if (calibration.pwm_zero_us > upper_us) {
        upper_us = calibration.pwm_zero_us;
    }
    if (calibration.pwm_max_us > upper_us) {
        upper_us = calibration.pwm_max_us;
    }
    return upper_us;
}

static uint16_t roundToUint16(float value) {
    return static_cast<uint16_t>(value + 0.5f);
}

static ArmJointPwmUs emptyPwm() {
    return {0, 0, 0, 0, 0};
}

static ArmJointAngles emptyAngles() {
    return {0.0f, 0.0f, 0.0f, 0.0f, 0.0f};
}

static TcpPose emptyPose() {
    return {0.0f, 0.0f, 0.0f};
}

const char *kinematicsStatusName(KinematicsStatus status) {
    switch (status) {
        case KinematicsStatus::Ok:
            return "Ok";
        case KinematicsStatus::OutOfReach:
            return "OutOfReach";
        case KinematicsStatus::JointLimitViolation:
            return "JointLimitViolation";
        case KinematicsStatus::JointLimitBlocked:
            return "JointLimitBlocked";
        case KinematicsStatus::NoProgress:
            return "NoProgress";
        case KinematicsStatus::NotImplemented:
            return "NotImplemented";
        case KinematicsStatus::InvalidInput:
            return "InvalidInput";
    }

    return "Unknown";
}

JacobianIkConfig defaultJacobianIkConfig() {
    return {
        0.02f,
        500,
        0.08f,
        20.0f,
        20.0f,
        1.0f,
        1.5f,
        1.5f,
        1.5f,
        1.5f,
        {0.5f, 0.5f, 0.5f, 0.5f, 0.5f},
        0.003f,
        0.02f,
        0.02f,
        0.0005f,
        25,
    };
}

KinematicsResult<uint16_t> jointAngleToPwmUs(
    uint8_t joint_index,
    float angle_rad,
    const JointCalibration calibrations[ROBOT_TOTAL_JOINT_COUNT]) {
    if (joint_index >= ROBOT_TOTAL_JOINT_COUNT || !isFiniteFloat(angle_rad)) {
        return {KinematicsStatus::InvalidInput, 0};
    }

    const JointCalibration &calibration = calibrations[joint_index];
    if (angle_rad < calibration.angle_min_rad || angle_rad > calibration.angle_max_rad) {
        return {KinematicsStatus::JointLimitViolation, 0};
    }

    const float pwm_us = interpolatePwmUs(calibration, angle_rad);
    if (!isFiniteFloat(pwm_us) ||
        pwm_us < static_cast<float>(lowerPwmBoundUs(calibration)) ||
        pwm_us > static_cast<float>(upperPwmBoundUs(calibration))) {
        return {KinematicsStatus::JointLimitViolation, 0};
    }

    return {KinematicsStatus::Ok, roundToUint16(pwm_us)};
}

KinematicsResult<ArmJointPwmUs> jointAnglesToPwmUs(
    const ArmJointAngles &angles,
    const JointCalibration calibrations[ROBOT_TOTAL_JOINT_COUNT]) {
    if (!isValidAngles(angles)) {
        return {KinematicsStatus::InvalidInput, emptyPwm()};
    }

    const float angle_values[] = {
        angles.j0_rad,
        angles.j1_rad,
        angles.j2_rad,
        angles.j3_rad,
        angles.j4_rad,
    };

    uint16_t pwm_values[] = {0, 0, 0, 0, 0};
    for (uint8_t i = 0; i < ROBOT_KINEMATIC_JOINT_COUNT; ++i) {
        const KinematicsResult<uint16_t> result = jointAngleToPwmUs(i, angle_values[i], calibrations);
        if (result.status != KinematicsStatus::Ok) {
            return {result.status, emptyPwm()};
        }
        pwm_values[i] = result.value;
    }

    return {
        KinematicsStatus::Ok,
        {
            pwm_values[0],
            pwm_values[1],
            pwm_values[2],
            pwm_values[3],
            pwm_values[4],
        },
    };
}
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

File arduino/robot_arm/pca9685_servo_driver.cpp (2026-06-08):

#include "pca9685_servo_driver.h"

Pca9685ServoDriver::Pca9685ServoDriver(const Pca9685ServoDriverConfig &config)
    : pca_(),
      config_(config),
      current_pwm_us_(),
      current_pwm_known_() {
}

bool Pca9685ServoDriver::begin() {
    const bool ok = pca_.begin();
    if (!ok) {
        return false;
    }

    pca_.setPWMFreq(config_.servo_frequency_hz);
    return true;
}

void Pca9685ServoDriver::setServoUs(uint8_t channel, uint16_t target_us) {
    if (channel >= CHANNEL_COUNT) {
        return;
    }

    writeServoUs(channel, target_us);
}

bool Pca9685ServoDriver::currentServoUs(uint8_t channel, uint16_t &pwm_us) const {
    if (channel >= CHANNEL_COUNT || !current_pwm_known_[channel]) {
        return false;
    }

    pwm_us = current_pwm_us_[channel];
    return true;
}

void Pca9685ServoDriver::writeServoUs(uint8_t channel, uint16_t pwm_us) {
    pca_.setPWM(channel, 0, pwmUsToTicks(pwm_us));
    current_pwm_us_[channel] = pwm_us;
    current_pwm_known_[channel] = true;
}

uint16_t Pca9685ServoDriver::pwmUsToTicks(uint16_t pwm_us) {
    uint32_t ticks = (static_cast<uint32_t>(pwm_us) * TICKS_PER_PERIOD) / SERVO_PWM_PERIOD_US;
    if (ticks >= TICKS_PER_PERIOD) {
        ticks = TICKS_PER_PERIOD - 1;
    }
    return static_cast<uint16_t>(ticks);
}

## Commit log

2026-05-26 feat: added wiring schema
    [project.csv, project.kicad_pcb, project.kicad_sch]
2026-05-30 feat: add home position script and joint calibration configuration
2026-05-30 feat: add joint calibration and demo dance scripts for robot arm
2026-05-30 feat: implement PCA9685 servo driver and integrate with demo dance and go home scripts
2026-06-01 feat: update joint calibration parameters and rename home references to zero in demo scripts
2026-06-01 feat: refactor code style and improve consistency in joint calibration and servo driver files
2026-06-01 feat: remove ramp functionality and simplify servo control in PCA9685 driver
2026-06-01 feat: add robot calibration structures and update demo scripts to use new calibration header
2026-06-01 feat: implement kinematics module with forward and inverse kinematics functions, add kinematics debug sketch, and update related scripts
2026-06-01 feat: enhance inverse kinematics with new functions and improve kinematics validation in debug scripts
2026-06-01 feat: refactor kinematics to use tool roll instead of yaw and update related trajectory calculations
2026-06-01 feat: add AGENTS.md for project overview, working style, decision framework, and engineering guidance
2026-06-02 Refactor kinematics and trajectory handling in robot arm code
    - Updated TcpPose structure to use yaw instead of pitch and yaw angles.
    - Renamed inverse kinematics functions to reflect changes in pose representation.
    - Modified trajectory computation to use updated inverse kinematics functions.
    - Improved comments for clarity on trajectory execution and TCP positioning.
    - Removed deprecated kinematics debug sketch to streamline the codebase.
    - Added home joint angles constants and functions for better initialization.
    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
2026-06-02 feat: enhance inverse kinematics with TCP offset pitch and refactor trajectory handling
2026-06-02 refactor: update kinematics calculations and simplify TCP pose representation
2026-06-02 refactor: simplify inverse kinematics logic and remove unused function
2026-06-02 feat: enhance inverse kinematics with explicit J3 pitch handling and update calibration for joint 3
2026-06-08 refactor: remove demo dance scripts and related kinematics files
2026-06-08 feat: add kinematics status name function and update target command handling
2026-06-08 feat: implement fixed Cartesian target sequence with multiple target commands
    [robot_arm.ino]
2026-06-08 docs: add detailed lessons learned section to improve calibration and kinematics understanding
2026-06-08 docs: add V1 limitations section to README for clarity on current constraints
2026-06-08 docs: add bill of materials and TODO sections to enhance project documentation
2026-06-08 docs: add source attribution for mechanical design and servo selection
2026-07-10 Implement Jacobian IK trajectory generation and enhance robot arm control
    - Introduced new structures for Jacobian IK configuration and results in kinematics.h.
    - Replaced hardcoded target commands with a dynamic TARGETS[] array in robot_arm.ino for a pick-and-place demo sequence.
    - Developed a non-blocking Jacobian IK motion control mechanism, allowing for smoother operation and responsiveness to commands.
    - Updated the moveToArmTarget function to utilize the new Jacobian IK approach, improving the handling of joint angles and PWM commands.
    - Enhanced diagnostics output for better debugging and monitoring of the IK process.
    - Removed obsolete files and updated the TODO documentation to refl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
    [kinematics.cpp, robot_arm.ino]
